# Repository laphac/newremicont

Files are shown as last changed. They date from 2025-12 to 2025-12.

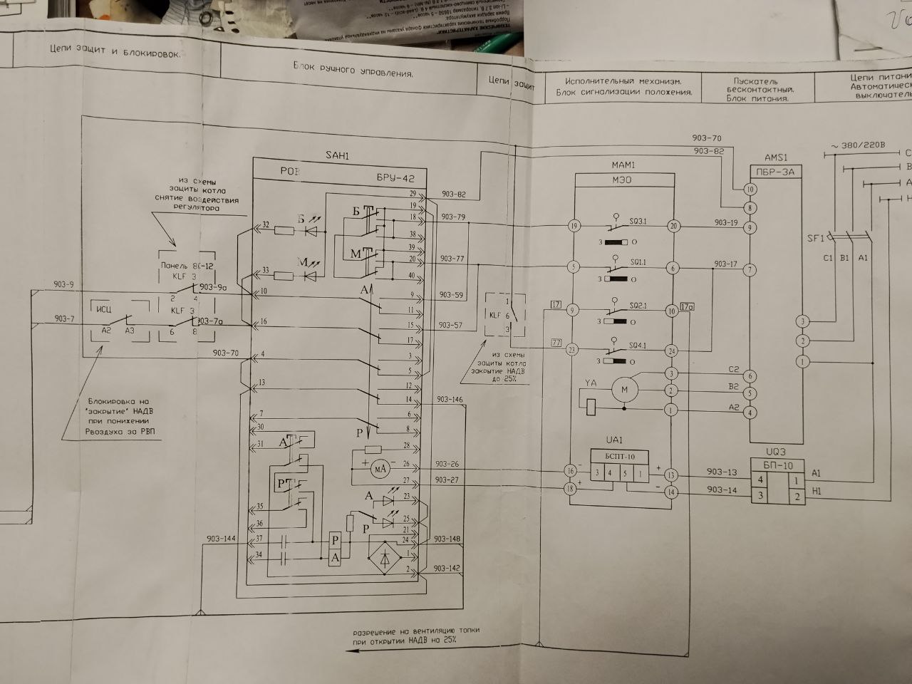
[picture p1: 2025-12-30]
image/photo_2025-12-30_14-42-51.jpg

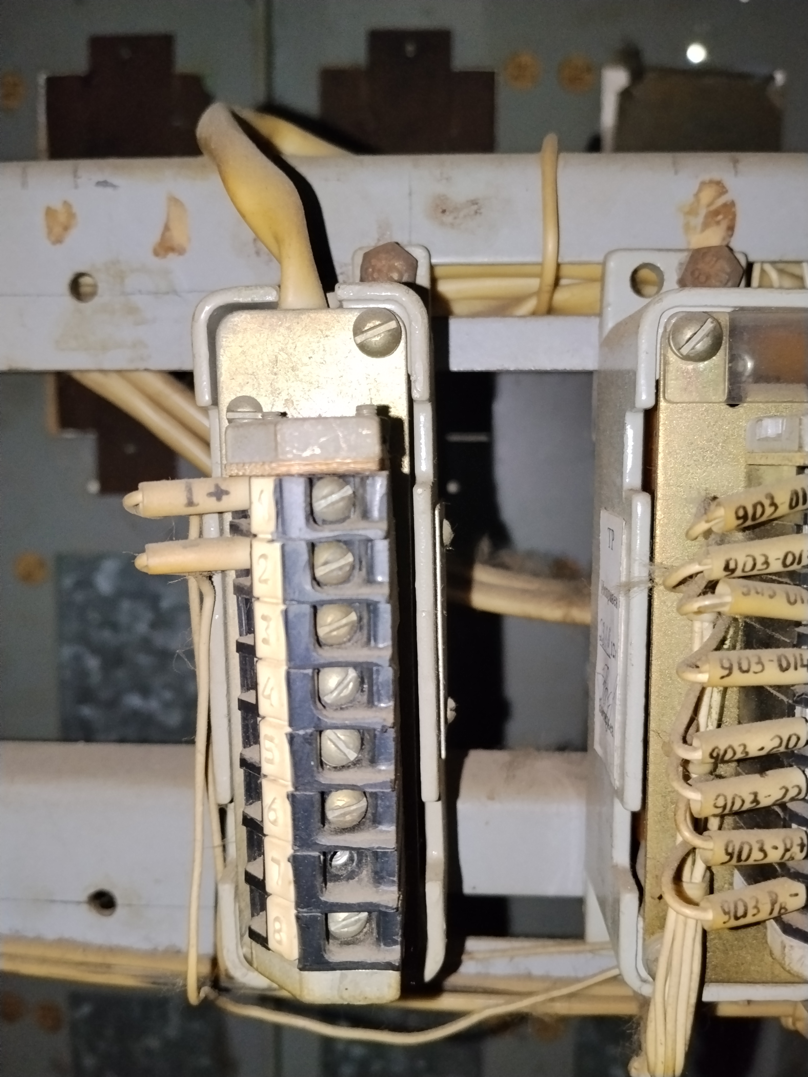
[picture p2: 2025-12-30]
image/IMG_20251224_152830.jpg

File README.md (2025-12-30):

# 🌬️ NewRemicont — Умный заменитель Ремиконт Р-130 для котлоагрегата ТГМЕ-464

> **Цель проекта**: Полная функциональная замена устаревшего регулятора общего воздуха (РОВ) **Ремиконт Р-130** на современный микроконтроллер **ESP32-C3** с веб-интерфейсом, ПИД-регулятором и поддержкой Modbus.  
> 🔌 **Подключение — контакт в контакт** к существующим разъёмам на торцевой панели Р-130. **Без переделки кабельной сети!**

[Рабочий интерфейс](screen/)

---

## 📌 Описание

Система автоматически поддерживает оптимальное содержание **кислорода в уходящих газах** котла ТГМЕ-464 за счёт двухуровневого управления давлением воздуха:

1. **Базовое соотношение "газ/воздух"** по 5-точечной таблице (аналог механической кулачковой характеристики Р-130).  
2. **Тонкая ПИД-коррекция** по отклонению O₂ от уставки с возможностью настройки коэффициентов через веб-интерфейс.

Управление исполнительным механизмом — через **4-канальное Modbus-реле** (импульсное: «больше» / «меньше»).

---

## 📦 Оборудование

| Компонент | Ссылка | Примечание |
|---|---|---|
| **ESP32-C3 DevKit** | [AliExpress](https://ali.click/xsw2to) | Основной контроллер |
| **Модуль АЦП ADS1115 (x2)** | [AliExpress](https://ali.click/evw2t8) | 4 дифференциальных канала |
| **Modbus-реле 4 канала** | [OZON](https://ozon.ru/t/6jMEk3t) | Адрес = 2, 9600 бод, 8N1 |

---

## 🔌 Схема подключения

Подключение выполнено **без изменений в существующей инфраструктуре** — используются только разъёмы от Р-130.

                               +------------------+
                               |    ESP32 DevKit  |
                               +------------------+
                               | 3V3   |  GND     |
                               | SDA(4)|  SCL(5)  |
                               | TX(0) |  RX(1)   |
                               +--------+---------+
                                        |  |  |
     +----------------+        +----------------+        +----------------+
     | ADS1115 #1     |        | ADS1115 #2     |        | Modbus Реле    |
     | (ADDR = GND)   |        | (ADDR = VCC)   |        | (Адрес = 2)    |
     +----------------+        +----------------+        +----------------+
     A0-A1 → O₂ датчик 1       A0-A1 → Расход газа       DATA+ → TX(0)
     A2-A3 → O₂ датчик 2       A2-A3 → Давление воздуха  DATA- → RX(1)
     VDD → 3.3V                VDD → 3.3V                GND → GND
     GND → GND                 GND → GND
     SDA → GPIO4 (общий)       SDA → GPIO4
     SCL → GPIO5 (общий)       SCL → GPIO5

Питание (+5V) для ESP и ADS1115 берется с платы Modbus реле.

Детальная схема блоков **КБС-2 / КБС-3** — см. в папке [`image/`](image/).

Все файлы необходимые для работы с технологической программой, драйвера, файл прошивки **и скриншоты установки** — см. в папке [`files/`](files/).

Файлы для 3-д печати **кейса (бокса)** — см. в папке [`3d-box/`](3d-box/).

---

## 💻 Прошивка ESP32-C3 под MicroPython

### Требования
- Python 3.7+
- `esptool`

### Инструкция по прошивке MicroPython на ESP32-C3

#### 1. Установка необходимых инструментов
Установите `esptool.py` — утилиту для работы с flash-памятью ESP.
```bash
pip install esptool
```

#### 2. Подготовка прошивки MicroPython
1.  Перейдите на официальную страницу загрузки: [micropython.org/download/ESP32C3/](https://micropython.org/download/ESP32C3/)
2.  Скачайте последнюю стабильную версию прошивки (файл с расширением `.bin`). Обычно это файл с названием, похожим на `ESP32_GENERIC_C3-20240222-v1.22.2.bin`.

#### 3. Определение COM-порта
Перед началом работы определите, какой COM-порт (на macOS/Linux — `/dev/ttyUSB*` или `/dev/ttyACM*`) назначен вашей ESP32-C3.
*   **Windows:** Диспетчер устройств -> Порты (COM и LPT).
*   **Linux/macOS:** Выполните в терминале `ls /dev/tty*` до и после подключения платы. Появившийся порт — ваш.

В последующих командах замените `<COM-порт>` на актуальное значение, например, `COM3`, `/dev/ttyUSB0`.

#### 4. Очистка flash-памяти (рекомендуется)
Перед записью новой прошивки полностью очистите память микроконтроллера.
```bash
esptool.py --port <COM-порт> erase_flash
```
**Примечание:** Использование `esptool.py` вместо `esptool` гарантирует вызов именно Python-скрипта. На некоторых системах оба варианта работают.

#### 5. Запись прошивки MicroPython
Выполните команду, указав путь к скачанному файлу прошивки. Ключ `--flash_size=detect` позволяет утилите автоматически определить размер памяти.
```bash
esptool.py --port <COM-порт> --baud 460800 write_flash --flash_size=detect 0 путь/к/файлу/прошивки.bin
```

#### 6. Загрузка вашего кода на устройство
После успешной прошивки ESP32-C3 будет запускать MicroPython. Чтобы загрузить ваши скрипты, можно использовать:

*   **Thonny IDE (самый простой способ):**
    1.  Установите [Thonny](https://thonny.org/).
    2.  Выберите `Инструменты -> Параметры -> Интерпретатор`.
    3.  Установите интерпретатор `MicroPython (ESP32)` и выберите ваш COM-порт.
    4.  Подключитесь, используя кнопку `Остановка/Перезапуск`.
    5.  Теперь вы можете редактировать и загружать файлы прямо на устройство.

#### 7. Точка входа и автозапуск
*   Скрипт `boot.py` выполняется **при каждой загрузке** устройства (включая сброс). Используйте его для начальной настройки (например, подключения к Wi-Fi).
*   **Важно:** Скопируйте все необходимые `.py`-файлы вашего проекта в корневую файловую систему ESP32.

#### Советы
*   Для первой загрузки рекомендуется создать простой `main.py` с выводом на печать, чтобы убедиться, что все работает.
*   Если устройство не отвечает, проверьте подключение, порт и попробуйте нажать кнопку `RST` (Reset) на плате.
*   Скорость `460800` можно снизить до `115200`, если возникают ошибки при записи.

Структура проекта

```bash
├── boot.py                 # Точка входа
├── ads1115.py              # Работа с АЦП
├── modbus_relay.py         # Управление реле
├── config_manager.py       # Конфигурация (калибровка, таблица, ПИД)
├── air_pressure_controller.py  # Логика двухуровневого регулятора
├── webserver.py            # Веб-сервер и API
├── url_decode.py           # Вспомогательная утилита
├── config.json             # Сохранённая конфигурация (пример)
│
├── image/                  # Схемы КБС-2 / КБС-3
├── screen/                 # Скриншоты интерфейса
├── 3d-box/                 # Модель корпуса (STEP / STL)
└── README.md               # Этот файл
```

🌐 Веб-интерфейс
После запуска ESP32 создаёт точку доступа:
```bash
SSID: ADS1115_Sensor
Пароль: 12345678
Адрес: http://192.168.4.1
```

Возможности:

Калибровка 4 датчиков (O₂, расход газа, давление)

Редактирование 5-точечной таблицы «газ/воздух»

Настройка ПИД-коэффициентов и уставки O₂

Ручное управление реле

Отображение текущих значений в реальном времени

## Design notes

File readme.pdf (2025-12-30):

# Документация: Автоматический регулятор давления воздуха с коррекцией по O₂

Цель системы: Поддержание оптимального содержания кислорода в уходящих газах котла за счёт двухуровневого управления давлением воздуха:

1. Базовое соотношение газ/воздух по таблице (5 точек)
2. Тонкая ПИД-коррекция по отклонению O₂ от уставки
Управление — через Modbus-реле (импульсное: "больше"/"меньше").

# Структура проекта

/main.py | — Точка входа, запуск AP и основного цикла
/ads1115.py | — Чтение данных с двух модулей ADS1115 (4 диф. канала)
/modbus_relay.py | — Управление 4-канальным Modbus-реле (адрес = 2)
/config_manager.py | — Загрузка/сохранение конфигурации (включая таблицу и ПИД)
/url_decode.py | — Декодирование URL-параметров
/webserver.py | — Веб-сервер: калибровка, управление, настройка регулятора
/air_pressure_controller.py — Двухуровневый авторегулятор (таблица + ПИД)

# Подключение оборудования

Устройство | ESP32 GPIO | Примечание
ADS1115 модуль 1 | SDA=4, SCL=5, ADDR=GND → 0x48 | Каналы 0-1, 2-3 → O₂ датчики
ADS1115 модуль 2 | SDA=4, SCL=5, ADDR=VCC → 0x49 | Канал 0-1 → расход газа, 2-3 → давление воздуха
Modbus-реле | TX=GPIO0, RX=GPIO1 (UART1) | Адрес устройства = 2, 9600 бод, 8N1
Wi-Fi | — | Режим точки доступа (AP)

⚠ Важно: GPIO0 — BOOT-пин! Убедитесь, что при старте он не заземлён.

# Каналы измерения

Канал | Назначение | Конфигурация по умолчанию
ch0 | O₂ датчик 1 | 0–1 В → 0–25 %
ch1 | O₂ датчик 2 | 0–1 В → 0–25 %
ch2 | Расход газа | 0–1 В → 0–100 м³/ч
ch3 | Давление воздуха | 0–1 В → 0–10 кПа

Все значения автоматически усредняются/масштабируются согласно калибровке в config.json .

Логика авторегулятора (air_pressure_controller.py )

### 1. Базовый уровень: таблица газ/воздух

При текущем расходе газа ( ch2 ) система линейно интерполирует целевое давление воздуха из таблицы air_fuel_table (5 точек). Пример:

{"gas": 50.0, "air_target": 3.5}

→ При расходе газа 50 м³/ч → целевое давление = 3.5 кПа.

### 2. Тонкий уровень: ПИД-коррекция по O₂

Измеряется среднее O₂ от двух датчиков.
Цель: O₂ = | o2_setpoint | (например, 3.5%).
ПИД-выход = | Kp·e + Ki·∫e·dt + Kd·de/dt
Результат — добавка к базовому давлению (коррекция).

### 3. Ограничение коррекции

Параметр | max_correction | (например, 0.8 кПа) ограничивает отклонение от базовой кривой.
Если ПИД требует больше — он обрезается до лимита.

### 4. Управление реле

Если коррекция > +0.1: включить реле 2 на | impulse_duration | сек → увеличить давление.
Если коррекция < –0.1: включить реле 1 на | impulse_duration | сек → уменьшить давление.
Иначе: HOLD (нет импульсов).
Управление происходит не чаще, чем раз в | control_interval | секунд.
⚙ Конфигурация ( config.json | )
Секция | auto_control | → переименована в | pid_control

"pid_control": {
"enabled": true,
"o2_setpoint": 3.5,
"deadband": 0.1,
"Kp": 0.8,
"Ki": 0.02,
"Kd": 0.1,
"max_correction": 0.8,
"control_interval": 10,
"impulse_duration": 1.5,
"pressure_min_safe": 0.5,
"pressure_max_safe": 9.0
}
Секция | air_fuel_table | (5 точек)

"air_fuel_table": [
{"gas": 0.0, "air_target": 1.0}, {"gas": 20.0, "air_target": 2.0}, {"gas": 50.0, "air_target": 3.5}, {"gas": 80.0, "air_target": 6.0}, {"gas": 100.0, "air_target": 8.5} ]

# Веб-интерфейс

Доступ: | http://192.168.4.1
SSID: | ADS1115_Sensor , пароль: | 12345678

### 1. Калибровка датчиков

Для каждого канала:
Напряжение (V_min – V_max) → Значение (Y_min – Y_max) + единица измерения

### 2. Таблица газ/воздух

Редактируемая таблица из 5 строк:
Расход газа (м³/ч) → Целевое давление (кПа)

### 3. ПИД-настройки

Включение/выключение
Уставка O₂, зона нечувствительности
Коэффициенты Kp, Ki, Kd
max_correction , control_interval , impulse_duration
Безопасные пределы давления

### 4. Ручное управление реле

Реле 1: "Меньше" (↓ давление)
Реле 2: "Больше" (↑ давление)
Реле 3–4: доступны для других задач

# Как работает "максимальная коррекция"?

Это предел отклонения от базовой кривой.
Если ПИД требует коррекцию +1.2 кПа, а max_correction = 0.8 → будет +0.8 кПа. Цель:
Не уходить в опасные режимы,
Сохранять смысл базовой таблицы,
Сигнализировать об ошибке: если коррекция = ±max —обновите таблицу!

# Алгоритм работы в цикле

1. Раз в control_interval секунд:
Считать напряжения с ADS1115
Применить калибровку → получить физические значения Определить базовое давление по таблице
Вычислить ошибку O₂
Рассчитать ПИД-коррекцию (с ограничением)
При необходимости — импульс реле 1 или 2
2. Параллельно: обработка HTTP-запросов (калибровка, управление, настройка)

# Диагностика и настройка

Симптом | Возможная причина | Решение
Нет импульсов, O₂ ≠ уставке | Таблица газ/воздух сильно ошибочна | Обновите точку в таблице
Постоянно коррекция = +0.8 | Недостаток воздуха по базовой кривой | Увеличьте air_target в таблице
Реле срабатывает, но давление не растёт | Механическая неисправность | Проверьте привод/вентилятор
O₂ "плавает" | Слишком высокий Kp | Уменьшите Kp, увеличьте control_interval

# Обновление базовой таблицы вручную

1. Откройте веб-интерфейс.
2. Посмотрите текущие значения:
Расход газа: ch2
Давление воздуха: ch3
Среднее O₂: (ch0 + ch1)/2
3. Если O₂ близок к уставке, но давление сильно отличается от таблицы —замените значение air_target для этого расхода газа.
4. Сохраните.

После этого коррекция ПИД приблизится к нулю → система работает оптимально.

# Заключение

Система реализует гибкий, безопасный и настраиваемый регулятор, сочетающий:

Инженерное знание (таблица газ/воздух)
Автоматическую адаптацию (ПИД по O₂)
Удобную настройку (веб-интерфейс)
Надёжное управление (Modbus-реле)

Совет: начните с грубой таблицы, затем корректируйте её на основе данных из веб-интерфейса.

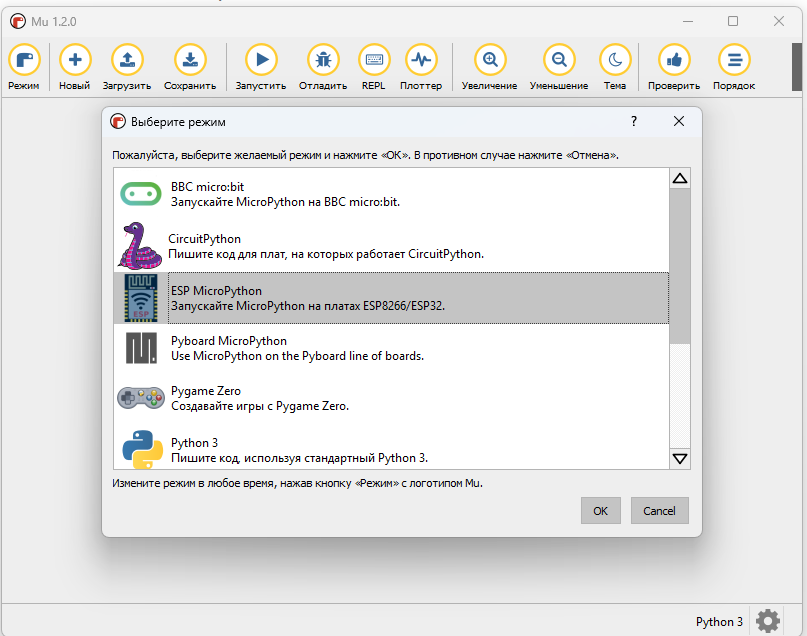
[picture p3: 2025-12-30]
files/Mu настройка.png

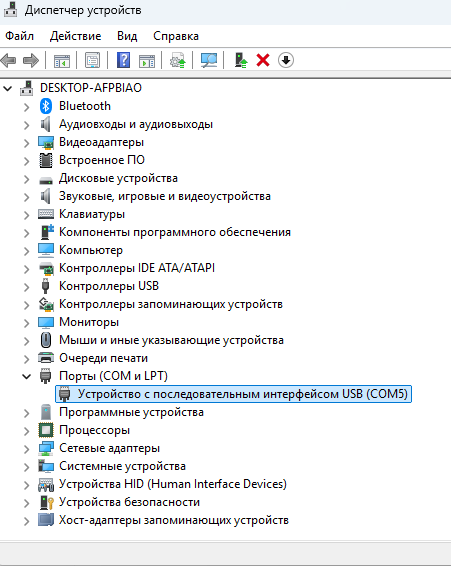
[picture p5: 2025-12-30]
files/0. Проверка что дрейвер подтянулся, либо установить.png

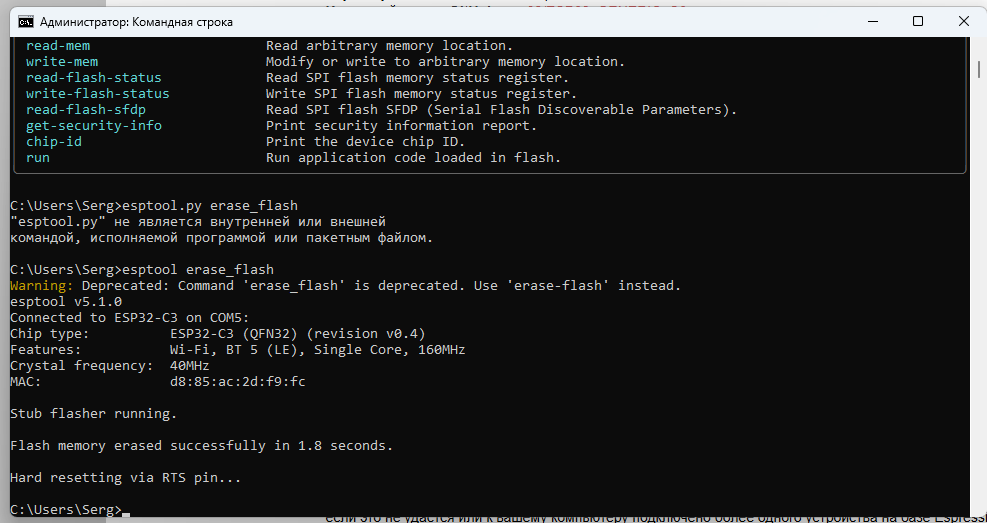
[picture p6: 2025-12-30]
files/2. Стирание старой памяти.png

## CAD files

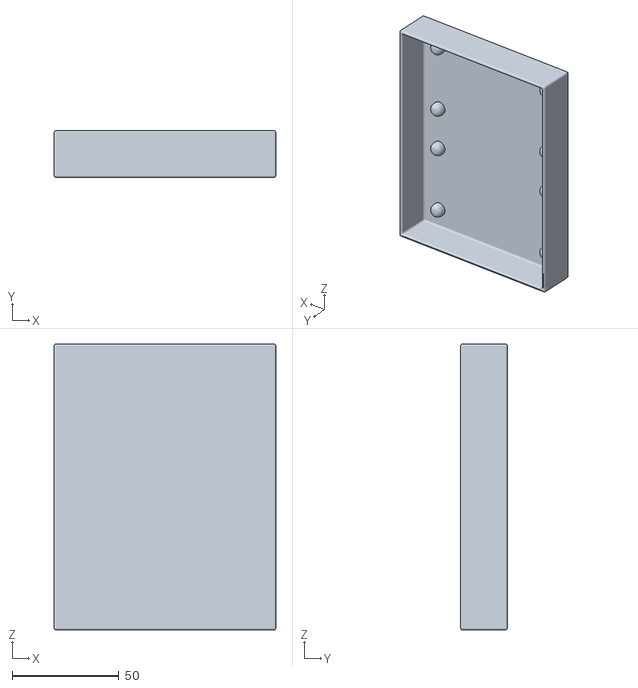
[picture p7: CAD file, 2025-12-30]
3d-box/Бокс под регулятор2.stl
104.0 x 22.0 x 134.0

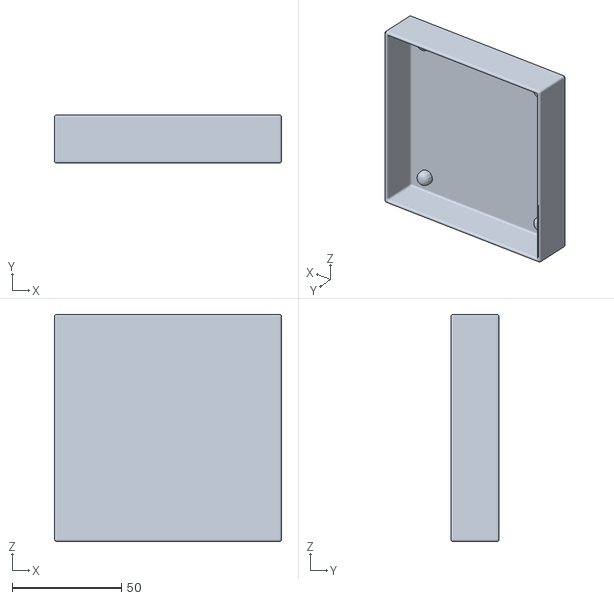
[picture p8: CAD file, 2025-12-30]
3d-box/Бокс под регулятор.stl
104.0 x 22.0 x 104.0

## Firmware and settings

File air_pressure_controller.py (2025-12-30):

# air_pressure_controller.py
import time
from ads1115 import read_all_channels
from modbus_relay import set_relay
from config_manager import load_config

# Глобальные переменные ПИД
_last_control_time = 0
_integral = 0.0
_last_error = 0.0

def apply_calibration(raw_voltages, config):
    """
    Применяет калибровку ко всем 4 каналам.
    Возвращает словарь с физическими значениями.
    """
    def v2y(v, key):
        ch = config[key]
        vmin, vmax = ch["v_min"], ch["v_max"]
        ymin, ymax = ch["y_min"], ch["y_max"]
        if vmax == vmin:
            return ymin
        return (ymax - ymin) / (vmax - vmin) * (v - vmin) + ymin

    return {
        "o2_1": v2y(raw_voltages[0], "ch0"),
        "o2_2": v2y(raw_voltages[1], "ch1"),
        "gas_flow": v2y(raw_voltages[2], "ch2"),
        "air_pressure": v2y(raw_voltages[3], "ch3"),
        "o2_avg": (v2y(raw_voltages[0], "ch0") + v2y(raw_voltages[1], "ch1")) / 2.0
    }

def linear_interpolate(x, table):
    """Интерполяция по таблице: список словарей с 'gas' и 'air_target'"""
    if not table:
        return 0.0
    if x <= table[0]["gas"]:
        return table[0]["air_target"]
    if x >= table[-1]["gas"]:
        return table[-1]["air_target"]
    for i in range(len(table) - 1):
        x0, y0 = table[i]["gas"], table[i]["air_target"]
        x1, y1 = table[i+1]["gas"], table[i+1]["air_target"]
        if x0 <= x <= x1:
            return y0 + (y1 - y0) * (x - x0) / (x1 - x0)
    return table[-1]["air_target"]

def run_automatic_control():
    global _last_control_time, _integral, _last_error
    cfg = load_config()
    pid = cfg.get("pid_control", {})
    
    if not pid.get("enabled", False):
        return {"status": "disabled"}

    now = time.time()
    interval = pid.get("control_interval", 10)
    if now - _last_control_time < interval:
        return None

    # === ЧИТАЕМ СЫРЫЕ НАПРЯЖЕНИЯ ===
    raw_voltages = read_all_channels()

    # === ПРИМЕНЯЕМ КАЛИБРОВКУ — ПОЛУЧАЕМ ФИЗИЧЕСКИЕ ЗНАЧЕНИЯ ===
    values = apply_calibration(raw_voltages, cfg)
    o2 = values["o2_avg"]
    gas = values["gas_flow"]
    pressure = values["air_pressure"]

    if None in (o2, gas, pressure):
        return {"error": "Invalid sensor data"}

    # === Уровень 1: базовое целевое давление по таблице ===
    air_target_base = linear_interpolate(gas, cfg.get("air_fuel_table", []))

    # Безопасность
    min_p = pid.get("pressure_min_safe", 0.5)
    max_p = pid.get("pressure_max_safe", 9.0)
    if pressure < min_p or pressure > max_p:
        return {"warning": f"Pressure out of safe range: {pressure:.2f}"}

    # === Уровень 2: ПИД-коррекция по O2 ===
    o2_setpoint = pid.get("o2_setpoint", 3.5)
    error = o2_setpoint - o2  # (+) → мало O2 → нужно больше воздуха

    deadband = pid.get("deadband", 0.1)
    if abs(error) <= deadband:
        correction = 0.0
        _integral = 0.0
        _last_error = 0.0
        action = "HOLD"
    else:
        dt = interval
        _integral += error * dt
        derivative = (error - _last_error) / dt if _last_error is not None else 0.0

        Kp = pid.get("Kp", 0.8)
        Ki = pid.get("Ki", 0.02)
        Kd = pid.get("Kd", 0.1)

        pid_output = Kp * error + Ki * _integral + Kd * derivative
        max_corr = pid.get("max_correction", 0.8)
        correction = max(-max_corr, min(max_corr, pid_output))

        _last_error = error

        # Управление реле (РЕЛЕ 1 = МЕНЬШЕ, РЕЛЕ 2 = БОЛЬШЕ)
        if correction > 0.1:
            # Нужно УВЕЛИЧИТЬ давление → включаем РЕЛЕ 2 ("больше")
            set_relay(4, True)   # ← было 1, стало 2
            time.sleep(pid.get("impulse_duration", 1.5))
            set_relay(4, False)
            action = "UP"
        elif correction < -0.1:
            # Нужно УМЕНЬШИТЬ давление → включаем РЕЛЕ 1 ("меньше")
            set_relay(3, True)   # ← было 2, стало 1
            time.sleep(pid.get("impulse_duration", 1.5))
            set_relay(3, False)
            action = "DOWN"

    _last_control_time = now
    return {
        "gas_flow": round(gas, 1),
        "air_target_base": round(air_target_base, 2),
        "air_pressure": round(pressure, 2),
        "o2_avg": round(o2, 2),
        "error": round(error, 2),
        "correction": round(correction, 2) if 'correction' in locals() else 0.0,
        "action": action
    }

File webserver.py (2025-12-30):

# webserver.py
import socket
from ads1115 import read_all_channels
from modbus_relay import set_relay
from config_manager import load_config, save_config
from url_decode import url_decode

def voltage_to_value(v, ch_cfg):
    vmin = ch_cfg["v_min"]
    vmax = ch_cfg["v_max"]
    ymin = ch_cfg["y_min"]
    ymax = ch_cfg["y_max"]
    if vmax == vmin:
        return ymin
    return (ymax - ymin) / (vmax - vmin) * (v - vmin) + ymin

def parse_post_data(data):
    try:
        if b'\r\n\r\n' in data:
            body = data.split(b'\r\n\r\n', 1)[1]
            body_str = body.decode('utf-8')
            params = {}
            for pair in body_str.split('&'):
                if '=' in pair:
                    k, v = pair.split('=', 1)
                    k = url_decode(k)
                    v = url_decode(v)
                    params[k] = v
            return params
    except Exception as e:
        print("POST parse error:", e)
    return {}

def handle_relay_request(params):
    try:
        ch = int(params.get("relay", "0"))
        action = params.get("action", "")
        if 1 <= ch <= 4 and action in ("on", "off"):
            set_relay(ch, action == "on")
    except Exception as e:
        print("Relay error:", e)

def build_web_page(voltages, cfg):
    html = """<!DOCTYPE html>
<html>
<head>
    <meta charset="UTF-8">
    <title>ADS1115 + Регулятор</title>
    <meta name="viewport" content="width=device-width, initial-scale=1">
    <style>
        body { font-family: Arial, sans-serif; margin: 10px; background: #f9f9f9; }
        h1, h2 { color: #2c3e50; }
        .channel, .relay, .table, .pid { background: white; padding: 14px; margin: 12px 0; border-radius: 8px; box-shadow: 0 2px 5px rgba(0,0,0,0.1); }
        input, button, select { padding: 6px; margin: 4px; }
        .num { width: 70px; }
        .unit { width: 50px; }
        .name { width: 120px; }
        button { background: #27ae60; color: white; border: none; border-radius: 4px; cursor: pointer; }
        button.off { background: #e74c3c; }
        .result { font-weight: bold; color: #e74c3c; font-size: 1.2em; }
        table { width: 100%; border-collapse: collapse; margin: 8px 0; }
        th, td { border: 1px solid #ccc; padding: 6px; text-align: center; }
        th { background: #f0f0f0; }
    </style>
</head>
<body>
    <h1>🎛️ Калибровка и управление</h1>
"""
    # === Каналы датчиков ===
    for i, (v, key) in enumerate(zip(voltages, ["ch0", "ch1", "ch2", "ch3"])):
        c = cfg[key]
        value = voltage_to_value(v, c)
        html += f"""
    <div class="channel">
        <strong>{c['name']}</strong><br>
        Напряжение: <code>{v:+.4f} В</code> → <span class="result">{value:.2f} {c['unit']}</span><br>
        <form action="/" method="POST">
            <input type="hidden" name="ch" value="{key}">
            Название: <input type="text" name="name" class="name" value="{c['name']}">
            Напряжение: 
            <input type="number" step="any" class="num" name="v_min" value="{c['v_min']}"> – 
            <input type="number" step="any" class="num" name="v_max" value="{c['v_max']}"> В<br>
            Значение: 
            <input type="number" step="any" class="num" name="y_min" value="{c['y_min']}"> – 
            <input type="number" step="any" class="num" name="y_max" value="{c['y_max']}">
            <input type="text" name="unit" class="unit" value="{c['unit']}">
            <button type="submit">💾 Сохранить</button>
        </form>
    </div>
"""

    # === Таблица газ/воздух ===
    table = cfg.get("air_fuel_table", [])
    # Убедимся, что 5 точек
    while len(table) < 5:
        table.append({"gas": 0.0, "air_target": 0.0})
    if len(table) > 5:
        table = table[:5]

    html += '<h2>📊 Базовое соотношение газ/воздух</h2>\n<div class="table">\n'
    html += '<form action="/table" method="POST">\n'
    html += '<table>\n<tr><th>Расход газа (м³/ч)</th><th>Целевое давление (кПа)</th></tr>\n'
    for i, point in enumerate(table):
        html += f'<tr><td><input type="number" step="0.1" class="num" name="gas_{i}" value="{point["gas"]}"</td>'
        html += f'<td><input type="number" step="0.1" class="num" name="air_{i}" value="{point["air_target"]}"</td></tr>\n'
    html += '</table>\n<button type="submit">💾 Сохранить таблицу</button>\n</form>\n</div>'

    # === ПИД-регулятор ===
    pid = cfg.get("pid_control", {})
    enabled = "checked" if pid.get("enabled", True) else ""
    html += f'''
    <h2>⚙️ ПИД-коррекция по O₂</h2>
    <div class="pid">
        <form action="/pid" method="POST">
            <label><input type="checkbox" name="enabled" value="on" {enabled}> Включить ПИД</label><br><br>

            Уставка O₂ (%): 
            <input type="number" step="0.1" class="num" name="o2_setpoint" value="{pid.get("o2_setpoint", 3.5)}"> ±
            <input type="number" step="0.1" class="num" name="deadband" value="{pid.get("deadband", 0.1)}"> %
            <br><br>

            ПИД-коэффициенты:<br>
            Kp: <input type="number" step="0.01" class="num" name="Kp" value="{pid.get("Kp", 0.8)}">
            Ki: <input type="number" step="0.001" class="num" name="Ki" value="{pid.get("Ki", 0.02)}">
            Kd: <input type="number" step="0.01" class="num" name="Kd" value="{pid.get("Kd", 0.1)}">
            <br><br>

            Макс. коррекция (кПа): 
            <input type="number" step="0.1" class="num" name="max_correction" value="{pid.get("max_correction", 0.8)}"><br>
            Интервал (сек): 
            <input type="number" step="1" class="num" name="control_interval" value="{pid.get("control_interval", 10)}">
            Импульс (сек): 
            <input type="number" step="0.1" class="num" name="impulse_duration" value="{pid.get("impulse_duration", 1.5)}">
            <br><br>

            Безопасные пределы давления:<br>
            <input type="number" step="0.1" class="num" name="pressure_min_safe" value="{pid.get("pressure_min_safe", 0.5)}"> — 
            <input type="number" step="0.1" class="num" name="pressure_max_safe" value="{pid.get("pressure_max_safe", 9.0)}">
            <br><br>

            <button type="submit">💾 Сохранить ПИД</button>
        </form>
    </div>
'''

    # === Ручное управление реле ===
    html += '<h2>🔌 Ручное управление реле</h2>'
    for ch in range(1, 5):
        html += f'''
    <div class="relay">
        <strong>Реле {ch}</strong>
        <form action="/relay" method="POST" style="display:inline;">
            <input type="hidden" name="relay" value="{ch}">
            <input type="hidden" name="action" value="on">
            <button type="submit">🟢 ВКЛ</button>
        </form>
        <form action="/relay" method="POST" style="display:inline;">
            <input type="hidden" name="relay" value="{ch}">
            <input type="hidden" name="action" value="off">
            <button type="submit" class="off">🔴 ВЫКЛ</button>
        </form>
    </div>
'''
    html += "</body></html>"
    return html
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
